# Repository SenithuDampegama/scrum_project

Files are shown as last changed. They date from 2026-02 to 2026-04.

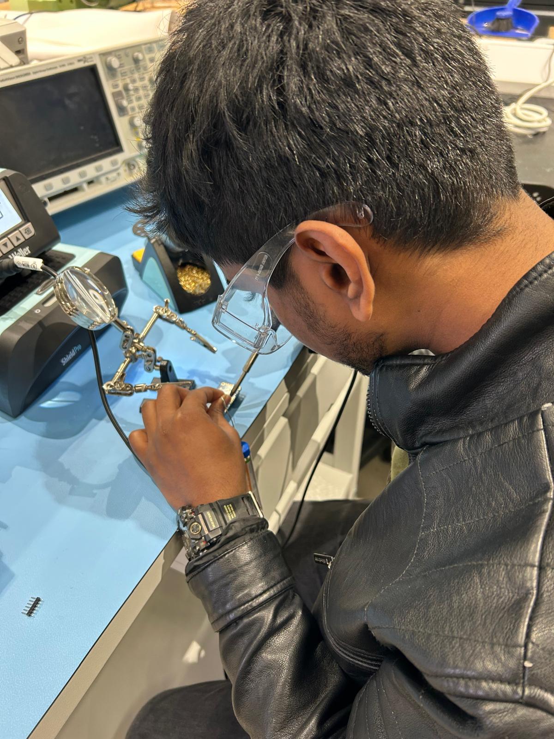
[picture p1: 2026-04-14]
docs/media/motor_controller/senithu.jpeg

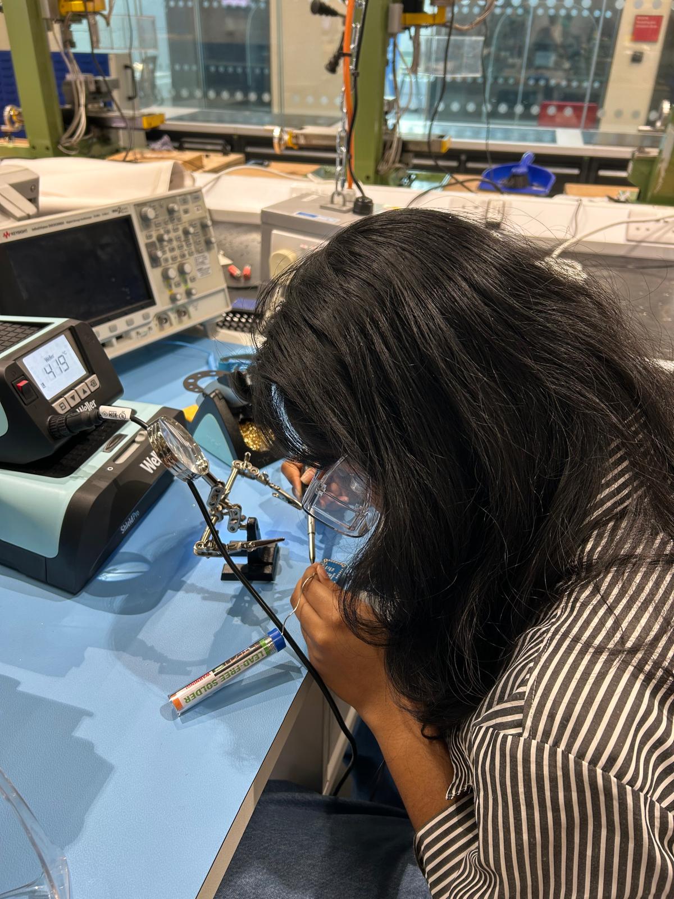
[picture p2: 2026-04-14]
docs/media/motor_controller/dinuli.jpeg

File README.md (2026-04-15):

# CDIO Scrum Robot Project



## Project Overview

This repository contains the implementation of a team-based robotics project developed under the **Conceive, Design, Implement, Operate (CDIO)** framework and managed using **Scrum** principles. The objective of the project is to design and build an autonomous walking robot capable of demonstrating multiple biologically inspired behaviours in a controlled environment.

The project was executed over **five sequential sprints**, each with a dedicated Scrum Master and a clearly defined set of deliverables. Although the development followed a logical engineering dependency order, Scrum artefacts such as sprint ownership, task tracking, and incremental delivery were maintained throughout the project.

---

## CDIO Tasks & Functional Requirements

The robot was required to satisfy the following core tasks:

* **Task 1 – Locomotion:** Enable the robot to walk using servo-driven mechanisms.
* **Task 2 – Object Avoidance:** Detect and avoid obstacles in the environment using distance sensors.
* **Task 3 – Phototaxis:** Move towards a bright light source and stop at approximately **20 cm** from it.
* **Task 4 – Predator Response:** Detect rapid motion in the environment, immediately stop movement, and deploy wings as a defensive response.

---

## Development Methodology

### CDIO Framework

The project followed the CDIO lifecycle:

* **Conceive:** System concept, behavioural definition, and mechanical feasibility analysis.
* **Design:** CAD modelling, electronics design, and system architecture definition.
* **Implement:** Hardware assembly, firmware development, and behaviour implementation.
* **Operate:** System testing, tuning, validation, and demonstration.

### Scrum Implementation

To align with Scrum methodology, the project was divided into **five sprints**, each led by a different Scrum Master. Each sprint produced tangible and reviewable outputs.

---

## Sprint Plan & Team Roles

| Sprint | Focus Area | Duration | Scrum Master |
| --- | --- | --- | --- |
| Sprint 1 | CAD Design | 4 weeks  | Dhanip Modi |
| Sprint 2 | Electronics Integration | 2 weeks  | Adwil Joshy |
| Sprint 3 | Robot Build | 1 week | Dinuli Jayaweera  |
| Sprint 4 | Programming & Behaviour Control | 2 weeks  | Senithu Dampegama |
| Sprint 5 | Testing & Validation | 1 week | Misba Babu |

The sprint order was selected to reflect real-world engineering dependencies, ensuring stable integration and reducing rework.

---

## Hardware Components

* Raspberry Pi Pico
* 10 × SG90 (180°) servo motors
* 2 × MG996R (360°) servo motors
* Adafruit BH1750 Light Sensor
* Adafruit PCA9685 Servo Driver
* Ultrasonic / IR distance sensors
* 9V battery and AA battery packs

---

## Software & Tools

* **Programming:** MicroPython / C++ (Pico)
* **CAD:** Fusion 360
* **Electronics Design:** Breadboard prototyping
* **Version Control:** Git & GitHub
* **Project Management:** GitHub Projects (Scrum Board)
* **Manufacturing:** 3D printing and laser cutting

---

## Repository Structure

```
cdio-scrum-robot/
├─ docs/                # Sprint documentation and reports
├─ cad/                 # CAD files and manufacturing exports
├─ electronics/         # Schematics, wiring, and BOM
├─ firmware/            # Pico firmware and control logic
├─ experiments/         # Calibration and tuning tests
└─ presentations/       # Final slides and demo media
```

---

## How to Run

1. Assemble the hardware according to the wiring diagrams in `electronics/`.
2. Flash the Raspberry Pi Pico with the firmware in `firmware/pico/`.
3. Power the system using the designated battery configuration.
4. Place the robot in a controlled environment with obstacles and a light source.

---

## Evidence & Demonstration

* Photos and videos of sprint deliverables are available in `docs/`.
* Final demonstration videos are available in `presentations/demo-videos/`.

---

## Project Management

All sprint tasks, issues, and progress tracking were managed using **GitHub Projects** following Scrum conventions. Each issue was labelled by sprint, owner, and task type.

---

## License

This project is released under the MIT License and is intended for academic and educational use only.

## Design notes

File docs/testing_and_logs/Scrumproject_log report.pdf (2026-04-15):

Student name
Total Sprints
Scrum Master | SPRINT 1 - Mechanical
Scrum Master | SPRINT 2 - Electronics
Scrum Master | SPRINT 3 - Robot Build
Scrum Master | SPRINT 4 - Software/Control
Scrum Master
Date | Work given | Name
3/2/2026 | Ordered Components in SPRINT 1 | Everyone
4th - 20th Feb | Components Designing Designing the Main body Sensor mountings Designing the Robot's Leg Designing the Wing Sprint 1 Review Submitted
4th - 20th Feb | | Modi Dhanip
4th - 20th Feb | | Adwil
4th - 20th Feb | | Dinuli
4th - 20th Feb | | Senithu
4th - 20th Feb | | Misba
17/02/2026
20/02/2026
Time Taken = 2 Week [24/03/2026 --> 09/03/2026]
Date | Work given | Name
24/2/2026 | Ordered Components in SPRINT 2 | Adwil
25/2/2026 | Soldering Motor controller Testing Ultrosonic sensors Testing Light sensor Testing servo motors Wiring of the robot Sprint 2 Review Submitted | Everyone
24/2/2026 | | Everyone
24/2/2026 | | Everyone
24/2/2026 | | Misba
3/3/2026 | | Dinuli
3/3/2026 | | Modi Dhanip
3/3/2026 | | Senithu, Adwil
6/3/2026 | | Adwil
Date | Work given | Name
10/3/2026 | No components were Ordered | Dinuli
9/3/2026 | MEETING 3- Planned for the Sprint 3 Wing attachment in Robot Build | Everyone
10/3/2026 | | Misba
10/3/2026 | Building the Lid of the robot Building the Legs of the Robot Connecting the Hip of the Robot Building the Main Body | Dinuli
10/3/2026 | | Modi Dhanip
10/3/2026 | | Senithu
10/3/2026 | | Adwil
20/03/2026 | Sprint 3 Review Submitted | Dinuli
Date | Work given | Name
17/03/2026 | No components were Ordered | Senithu
16/03/2026 | MEETING 4- Planned for the Programming week | Senithu
17th-24th Mar | Programming on predator Programming on Phototaxis Programming on Obstacle Avoidance Calibration of motors and Locomotion | dinuli
17th-24th Mar | | Modi Dhanip
17th-24th Mar | | Misba
17th-24th Mar | | Senithu
17th-24th Mar | Subsumption Sprint 4 Review Submitted | Adwil
27/03/2026 | | Senithu
Date | Work given | Name
10/4/2026 | Meeting 5- Planned for the Testing and Documentation Testing Locomotion and Calibration | Everyone
13/04/2026 | | Senithu
13/04/2026 | Testing Predator response code Testing Obstacle Avoidance | Dinuli
13/04/2026 | | Misba
13/04/2026 | Testing Phototaxis | Dhanip
14/04/2026 | GitHub, Wiring Diagram Gantt chart, Block Diagram | Senithu
14/04/2026 | | Dhanip
14/04/2026 | Flowchart, Hardware component List, Buy List | Misba
14/04/2026 | Presentation Slides | Adwil
14/04/2026 | Components list, Testing and Result List | Dinuli
17/04/2026 | Sprint 5 Review Submitted | Misba

5
Modi Dhanip
Adwil Joshy
Dinuli Jayaweera
Senithu Dampegama
Misba Fathima Babu
Time Taken = 4 Weeks [03/02/2026 --> 22/02/2026]

SPRINT 2 = ADWIL JOSHY

SPRINT 3 = DINULI

SPRINT 4 = SENITHU

SPRINT 5 = MISBA

Prepared Budget list for the components | Misba

MEETING 2- Discussed about the Electronics Soldering Light sensor, Motor controller

Modi Dhanip

Time Taken = 2 Week [17/03/2026 --> 27/03/2026]

Time Taken = 1 Week [13/04/2026 --> 19/04/2026]

Time Taken = 1 Week [10/03/2026 --> 16/03/2026]

SPRINT 1 = MODI DHANIP

MEETING 1- Discussed about the CAD design | Everyone

### SCRUM PROJECT LOG REPORT

DETAILS
Modi Dhanip, Senithu, Adwil, Dinuli, Misba

SPRINT 5 - Testing and Document

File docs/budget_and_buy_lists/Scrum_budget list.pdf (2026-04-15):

Category | Component | Quantity | Unit Cost (£) | Total Cost (£)
Electronics | Pico Board | 1 | £ 4.50 | £ 4.50
Electronics | SG90 Servo | 10 | £ 4.00 | £ 40.00
Electronics | BH1750 Light Sensor | 1 | £ 5.00 | £ 5.00
Electronics | HC-SR04 Ultrasonic | 2 | £ 2.00 | £ 4.00
Electronics | Micro USB Cable | 1 | £ 3.50 | £ 3.50
Electronics | Breadboard | 1 | £ 7.00 | £ 7.00
Manufacturing | 3D Printing (350g incl. buffer) | 230 | £ 0.02 | £ 4.60
Assembly | M3 Bolts (10mm) | 10 | £ 0.40 | £ 4.00
Assembly | M3 Bolts (30mm) | 3 | £ 0.50 | £ 1.50
Assembly | M3 Bolts (20 mm) | 4 | £ 0.45 | £ 1.80
Assembly | M3 Nuts | 13 | £ 0.05 | £ 0.65
Assembly | M3 Washers | 0 | £ 0.05 | £ -
Power | 4x AA Battery Holder | 1 | £ 1.50 | £ 1.50
Power | AA Batteries | 4 | £ 0.30 | £ 1.20
Power | 9V battery stud connector | 1 | £ 0.75 | £ 0.75
Power | PCA9685 motor controller | 1 | £ 15.00 | £ 15.00
| | | Subtotal | £ 95.00
| | | Contingency (20%)£ | 20.00

BUDGET LIST

Final Total | £ | 115.00

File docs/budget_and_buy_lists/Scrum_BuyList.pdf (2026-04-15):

Category | Component | Quantity | Unit Cost (£) | Total Cost (£)
Electronics | Pico Board | 1 | £ 4.50 | £ 4.50
Electronics | SG90 Servo | 10 | £ 4.00 | £ 40.00
Electronics | BH1750 Light Sensor | 1 | £ 5.00 | £ 5.00
Electronics | HC-SR04 Ultrasonic | 2 | £ 2.00 | £ 4.00
Electronics | Micro USB Cable | 1 | £ 3.50 | £ 3.50
Electronics | Breadboard | 1 | £ 7.00 | £ 7.00
Manufacturing | 3D Printing (350g incl. buffer) | 285.41 | £ 0.02 | £ 5.71
Assembly | M3 Bolts (10mm) | 10 | £ 0.40 | £ 4.00
Assembly | M3 Bolts (30mm) | 3 | £ 0.50 | £ 1.50
Assembly | M3 Bolts (20 mm) | 4 | £ 0.45 | £ 1.80
Assembly | M3 Nuts | 16 | £ 0.05 | £ 0.80
Assembly | M3 Washers | 11 | £ 0.05 | £ 0.55
Power | 4x AA Battery Holder | 1 | £ 1.50 | £ 1.50
Power | AA Batteries | 4 | £ 0.30 | £ 1.20
Power | 9V battery stud connector | 2 | £ 0.75 | £ 1.50
Power | PCA9685 motor controller | 1 | £ 15.00 | £ 15.00
| | | Subtotal | £ 97.56

BUY LIST

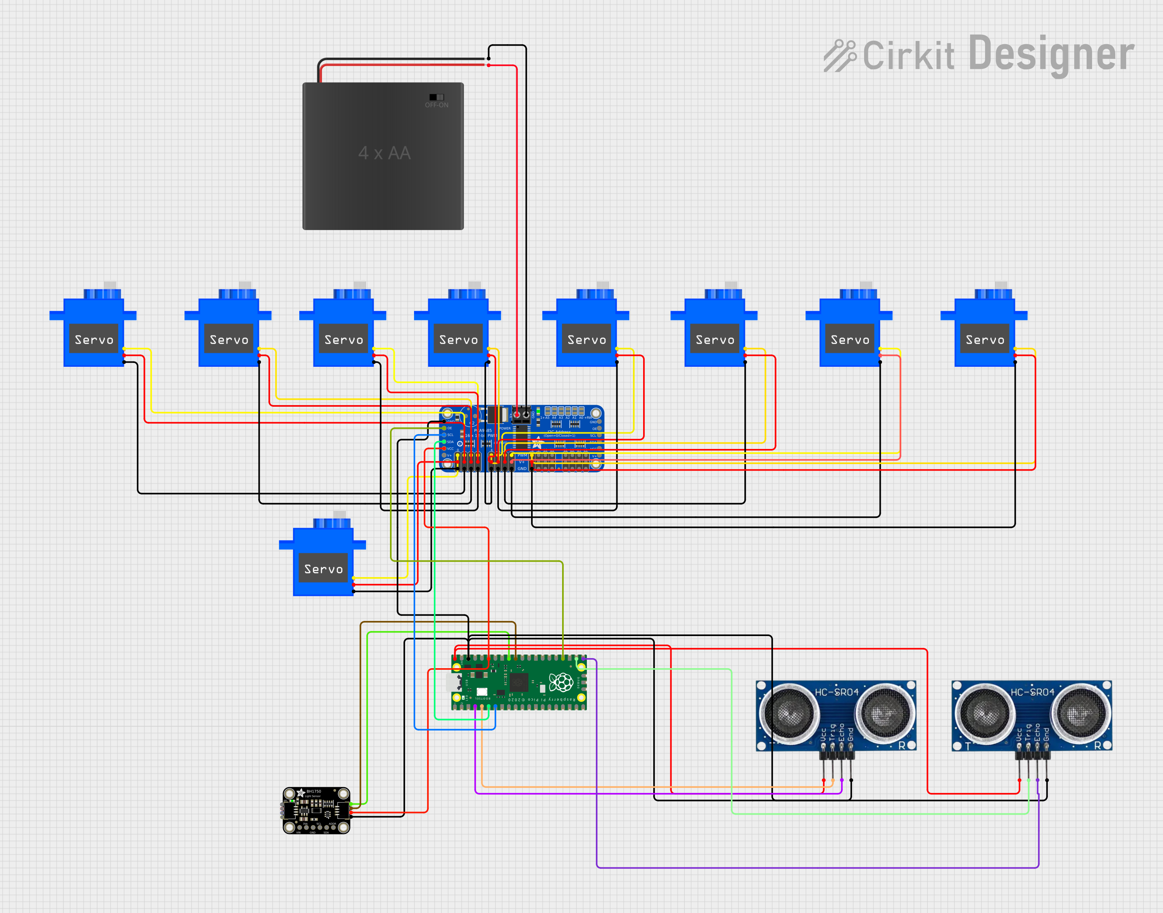
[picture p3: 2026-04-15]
docs/flowcharts_and_diagrams/circuit_image.png

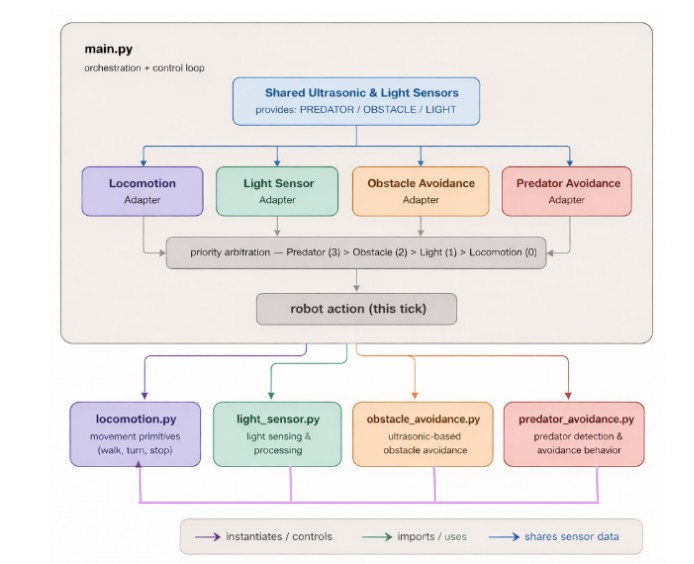
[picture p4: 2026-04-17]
docs/flowcharts_and_diagrams/Block_diagram.jpeg

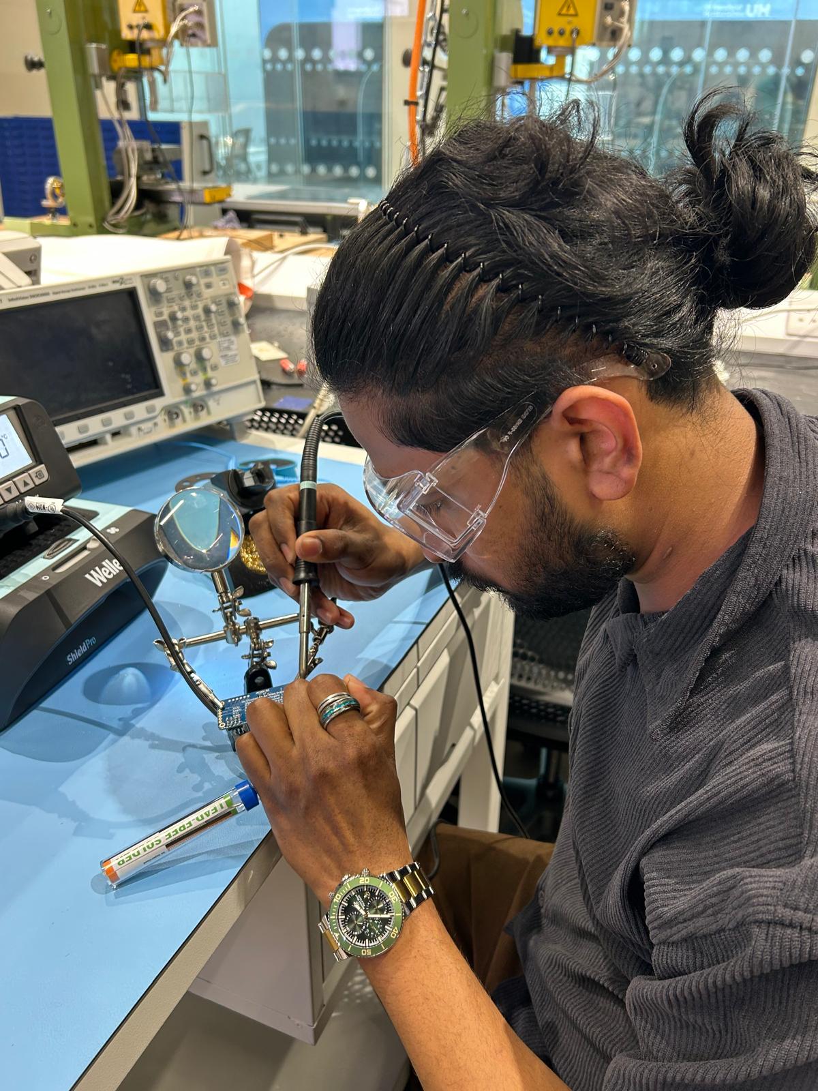
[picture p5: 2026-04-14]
docs/media/motor_controller/adwil.jpeg

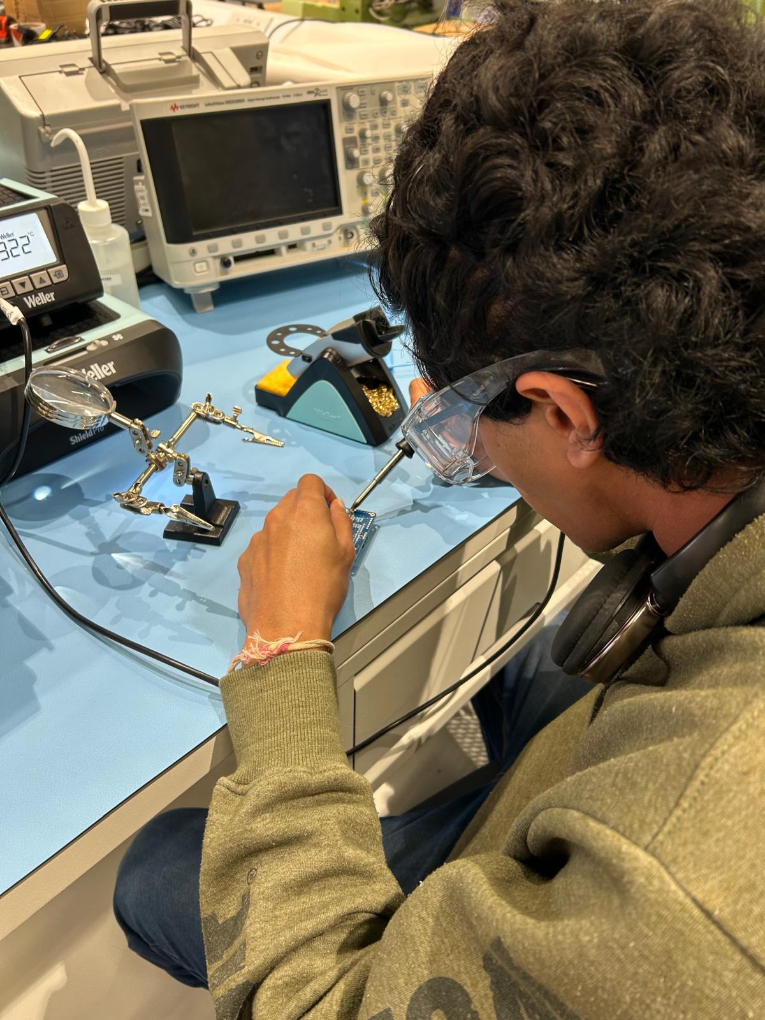
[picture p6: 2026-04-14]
docs/media/motor_controller/dhanip.jpeg

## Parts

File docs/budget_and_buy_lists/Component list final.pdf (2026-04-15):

Hardware Component List | No. of components
HC-SR04 Ultrasonic sensors | 2
BH1750 Light sensor | 1
Rasberry Pi Pico Board | 1
SG90 motors | 9
AA battery | 4
PCA9685 Motor Controller | 1
Battery Holder for 4 AA batteries | 1
9V battery stud connector | 1
Micro USB cable | 1
Total | 21

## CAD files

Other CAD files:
cad/components/Dhanip_Breadboard final - F1.f3d
cad/components/Dhanip_Microcontroller f.f3d
cad/components/Dhanip_light-sensor.f3d
cad/components/Dhanip_servo-arm.f3d
cad/components/Dhanip_servo-final.f3d
cad/components/Dinuli_Ultrasonic.f3d
cad/lid/Dinuli_Lid_Last.f3z
cad/locomotion/final_assembly/SENITHU_FINAL_ASSEMBLY.f3z
cad/locomotion/parts/SENITHU_ankel.f3d
cad/locomotion/parts/SENITHU_hip.f3d
cad/locomotion/parts/SENITHU_knee.f3d
cad/locomotion/parts/SENITHU_leg_L.f3d
cad/locomotion/parts/SENITHU_leg_R.f3d
cad/main_body/Adwil_Main_Body.f3z
cad/wing/Misba_Wing.f3d
cad/wing/Misba_Wing_Attachement.f3d

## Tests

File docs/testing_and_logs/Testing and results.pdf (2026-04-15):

. | Problems | Solutions

Sprint 1

Initially, we were not planning to use the motor controller, or the battery, therefore the design changed several times.

The design was changed, and we came up with integrating them on lid, so design of it was changed, and printed accordingly

The robot's height wasn't planned, and there was less space for the wires inside.

The robot height was adjusted and the body was reprinted with the correct height.
The wing had less width, and therefore was
fragile. | The wing width was fixed, and made sure it was strong.
Legs were initially bigger, causing friction. | The size of the legs was decreased and printed
The locations of the ultrasonic sensors, wings, light sensor were changed due to space management. | The locations were planned accordingly, space was
| managed, and the required CAD parts were printed on
| time.

Sprint 2

The power for the servos together wasn't enough | A separate power supply was used for servos, which was
| power supply from batteries.

Sprint 3

The connection of the wing and the body was
challenging since there was slight place in the wing connection.

We reduced the complexity by using equipments to handle the bolts.
The servo bolts were too small compared to the holes printed.

The materials were reprinted with smaller holes that fit into the bolt.

The robot was tested several times, as the wing motor started glitching, since the angles for it were wrong. Next, I tested the code several times, for changing the threshold values and finding the best values for the Sprint 4 robot. | The wing motor was replaced with the extra motor we bought, as the motor was burnt and not functioning well, and the angles were premeasured and adjsuted before it was integrated with the wing. To decide the threshold values, the test was carried out several times and decided.
The robot initially had an issue with moving slow, since there was larger friction. Once it was solved, there was a problem with the turnings, where the robot didn't make clear turns. | As a solution for the drag issue, the wave gate movement was shifted to crawl gate movement. The clear turns were made by finetuning the threshold values.

Sprint 5 | The robot is confusing the detections of obstacle and predator, since predator has the higher priority, obstacle avoidance doesn't override even when there is an obstacle. A subsumption is made in a way that both works.
| Subsumption architecture was changed as the previous Integration wasn't successful, as the priorities code had some issues. The new code works perfectly didn't work as expected according to the priorities.

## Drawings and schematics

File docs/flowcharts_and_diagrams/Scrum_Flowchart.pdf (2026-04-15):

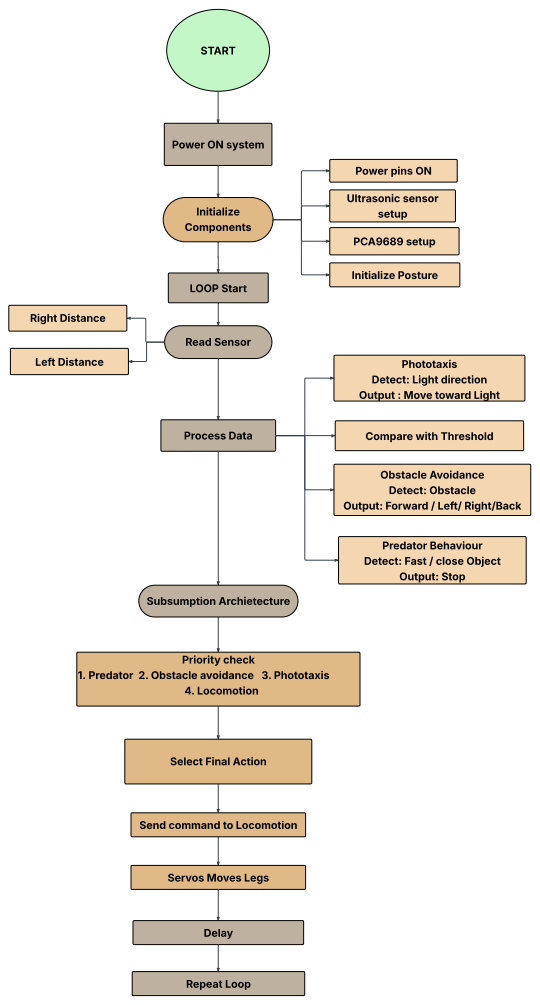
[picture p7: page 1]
START; Initialize Components; Ultrasonic sensor setup; PCA9689 setup; Initialize Posture; LOOP Start; Read Sensor; Left Distance; Right Distance; Process Data; Compare with Threshold; Subsumption Archietecture; Obstacle Avoidance Detect: Obstacle; Priority check; 4. Locomotion; Delay; Repeat Loop

Power ON system

Power pins ON

Phototaxis
Detect: Light direction
Output : Move toward Light

Output: Forward / Left/ Right/Back

Predator Behaviour
Detect: Fast / close Object
Output: Stop

1. Predator 2. Obstacle avoidance 3. Phototaxis

Select Final Action

Send command to Locomotion

Servos Moves Legs

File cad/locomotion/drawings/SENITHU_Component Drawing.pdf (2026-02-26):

A

2 | 3 | 4 | 5 | 6 | 7 | 8

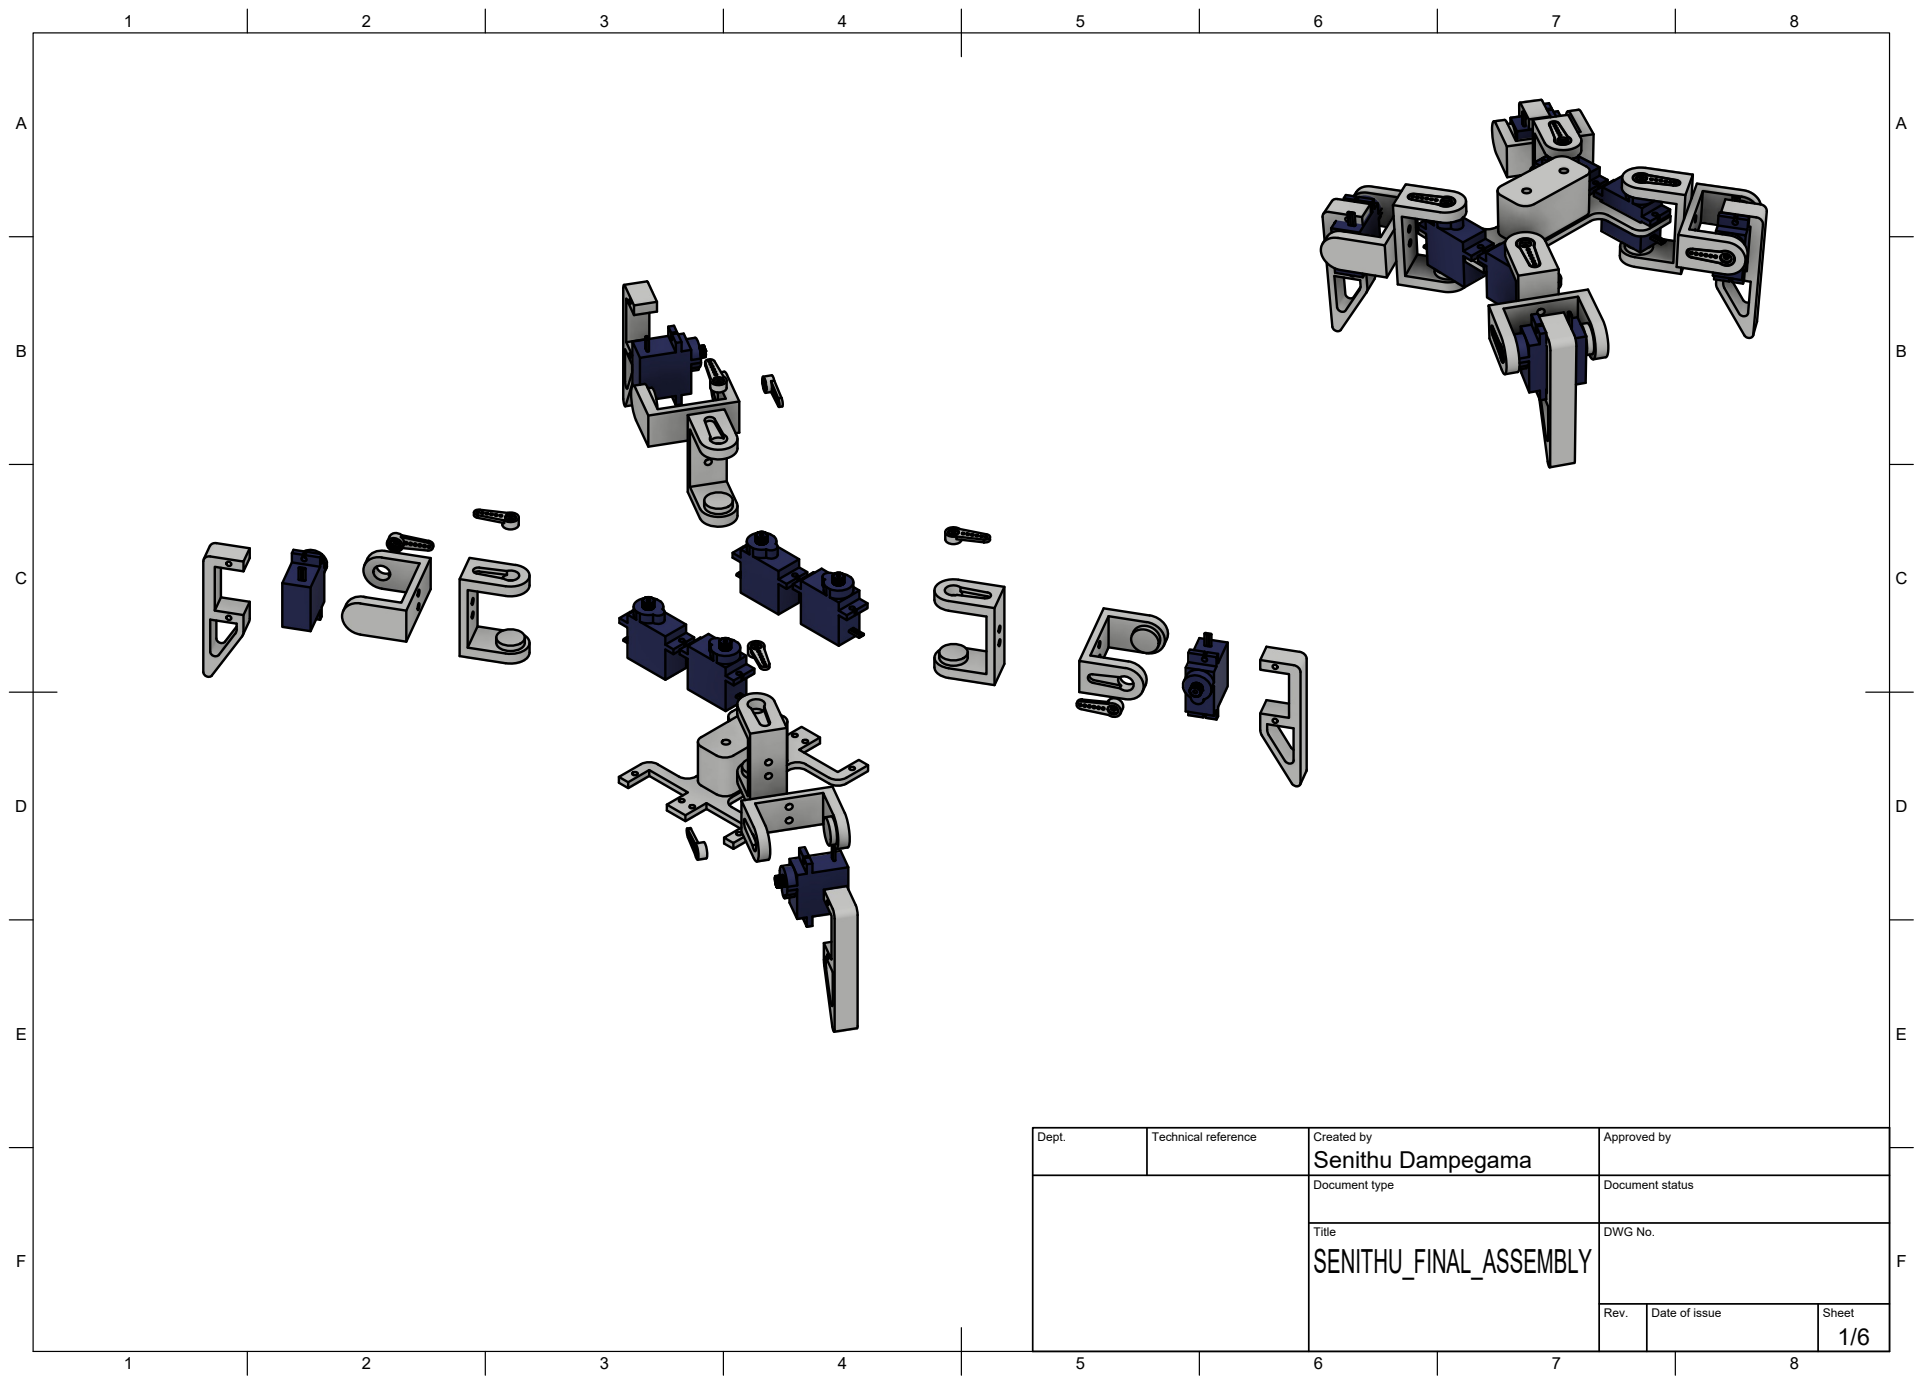
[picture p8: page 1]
Dept.; Technical reference; Created by; Approved by; Document type; Document status; Title; DWG No.; Rev.; Date of issue; Sheet; SENITHU_FINAL_ASSEMBLY; Senithu Dampegama

A

A

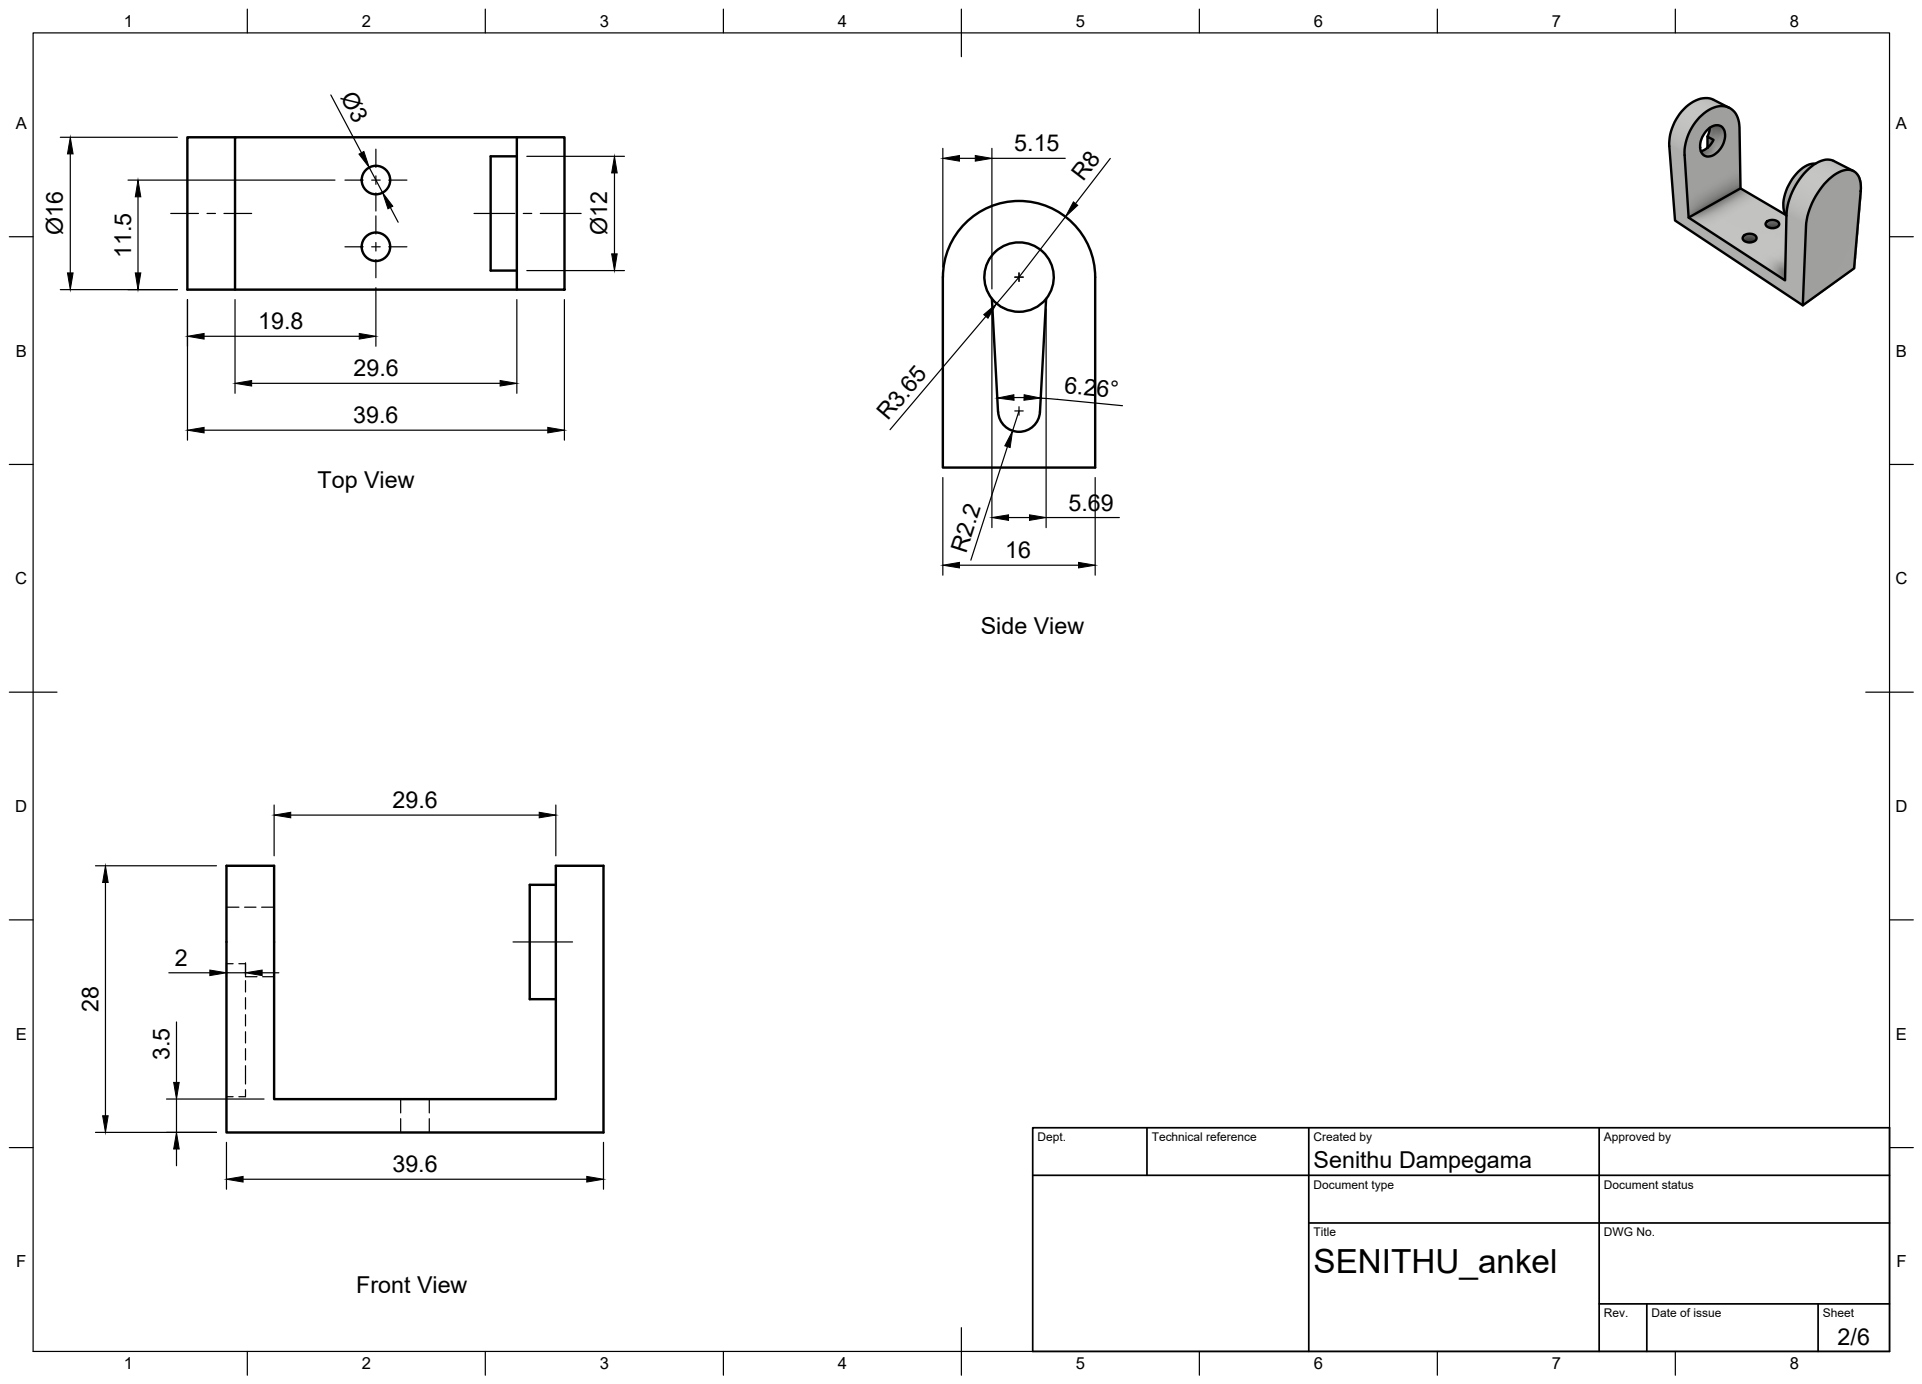
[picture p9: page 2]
Dept.; Technical reference; Created by; Approved by; Document type; Document status; Title; DWG No.; SENITHU_ankel; Senithu Dampegama; 39.6 Ø¹⁶; Ø¹²; Top View; Front View; Side View

A

A

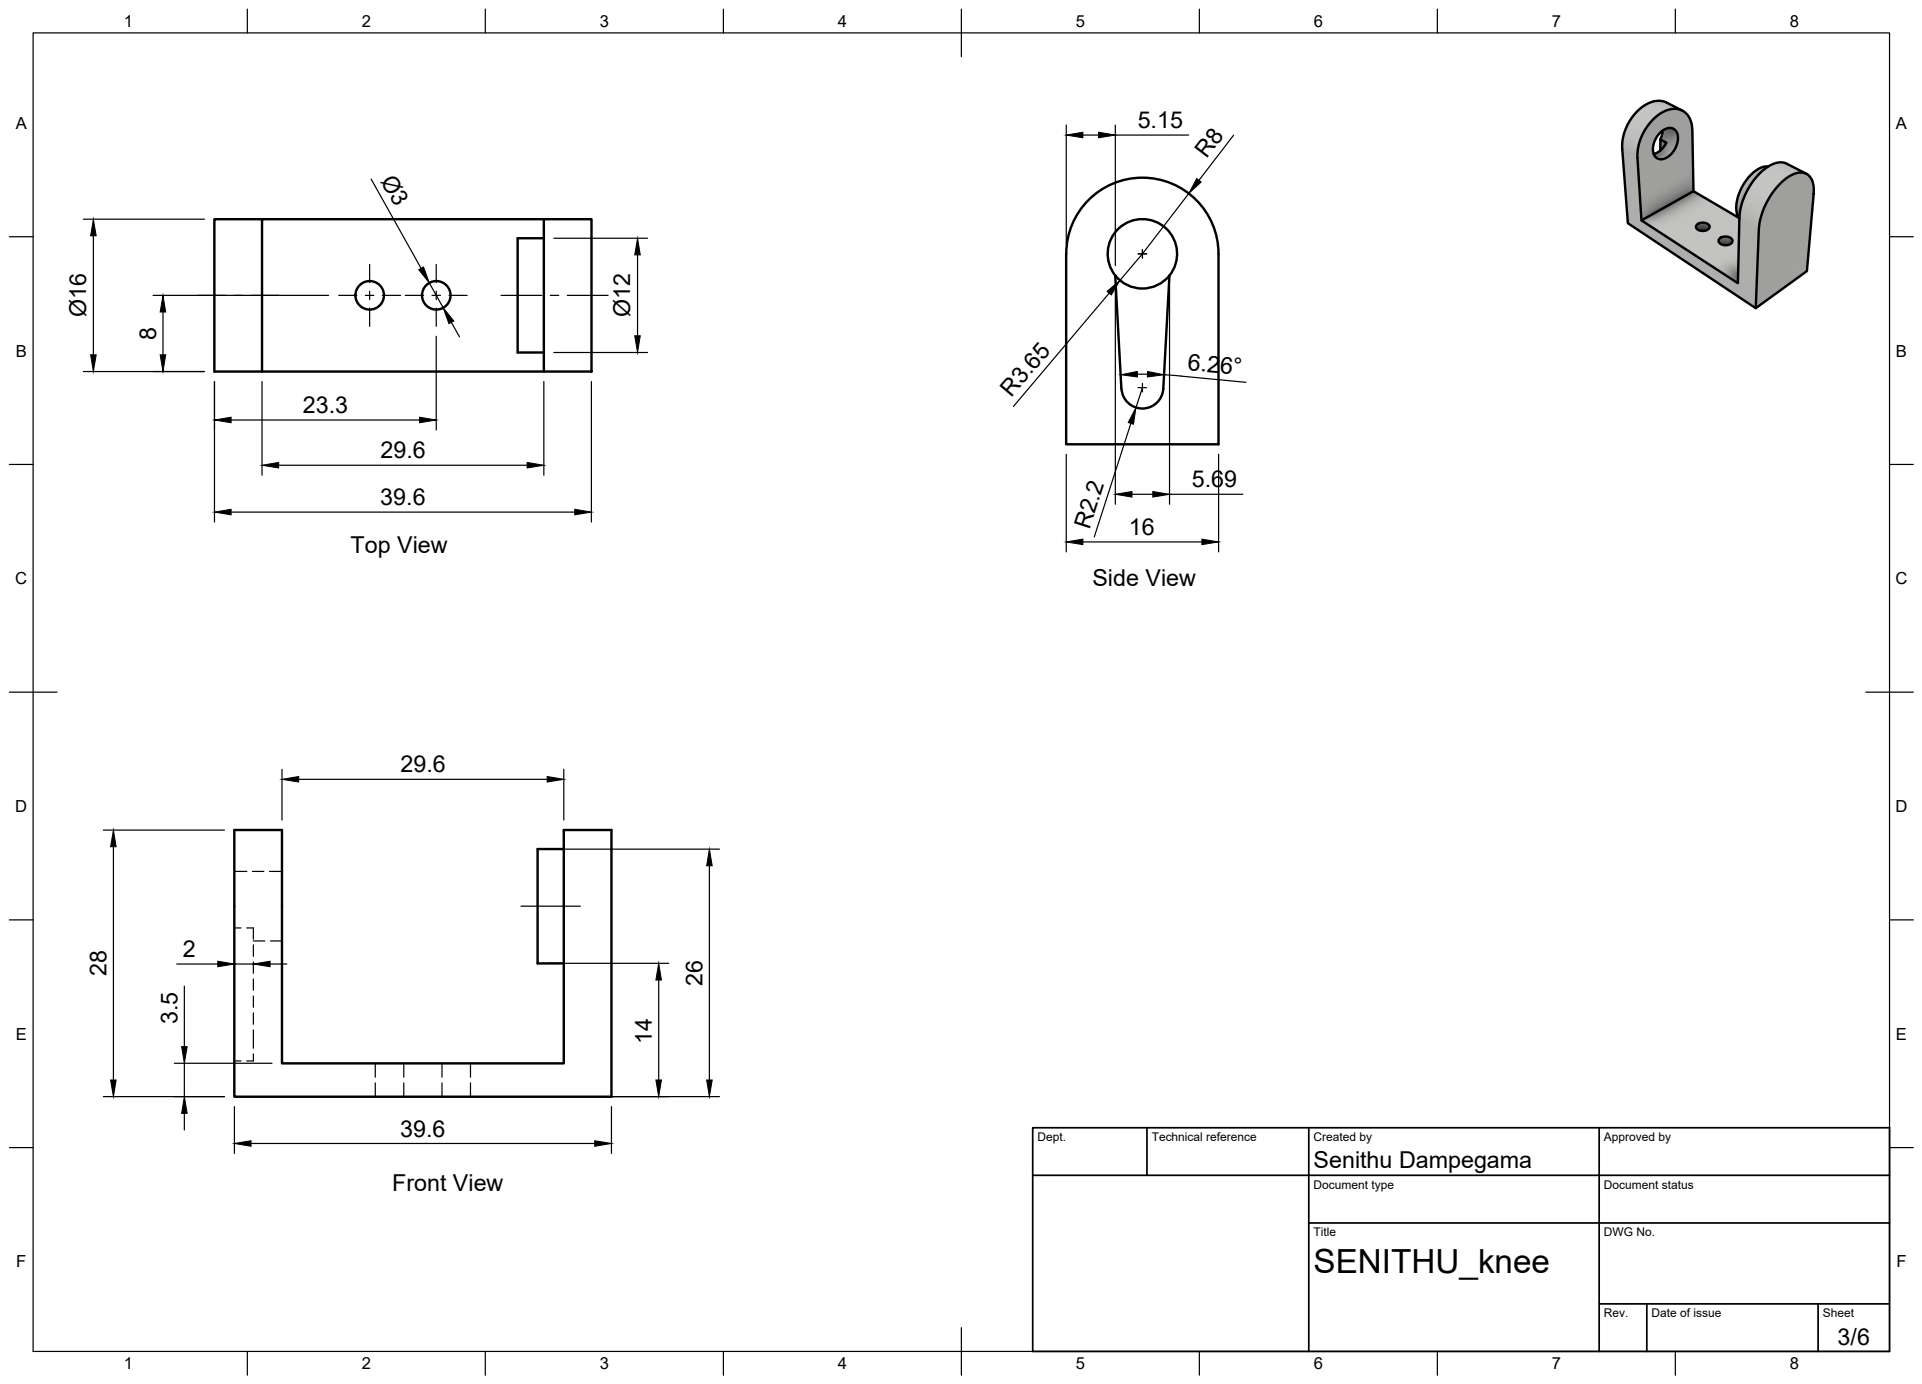
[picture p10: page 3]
Dept.; Technical reference; Created by; Approved by; Document type; Document status; Title; DWG No.; SENITHU_knee; Senithu Dampegama; 39.6 Ø¹⁶; Top View; Front View; Side View

A

A

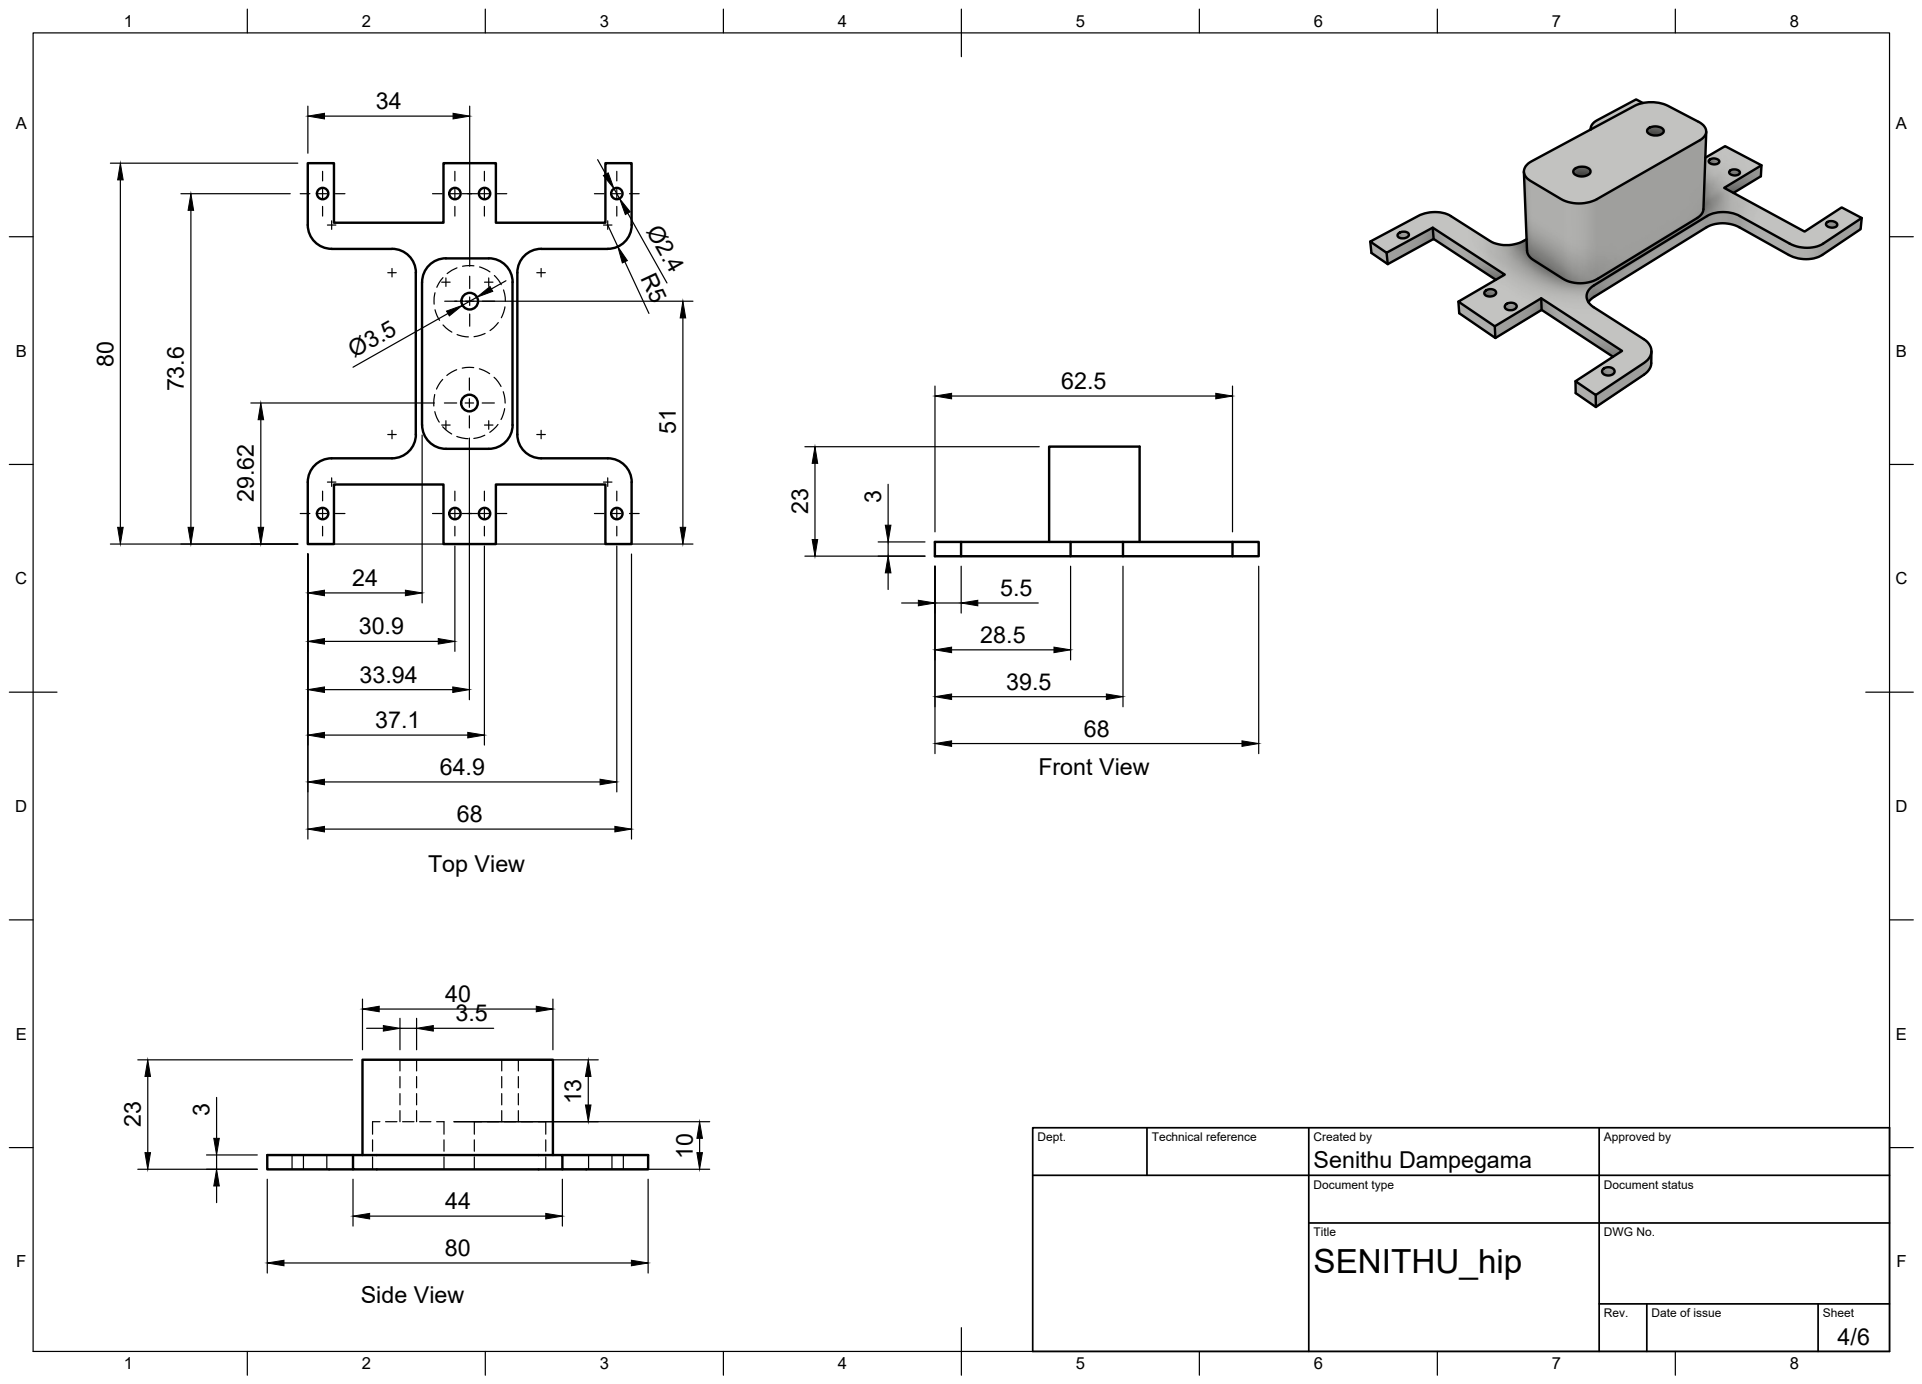
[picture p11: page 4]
Dept.; Technical reference; Created by; Approved by; Document type; Document status; Title; DWG No.; SENITHU_hip; Top View; Side View; Front View

Senithu Dampegama ⁸⁰

A

A

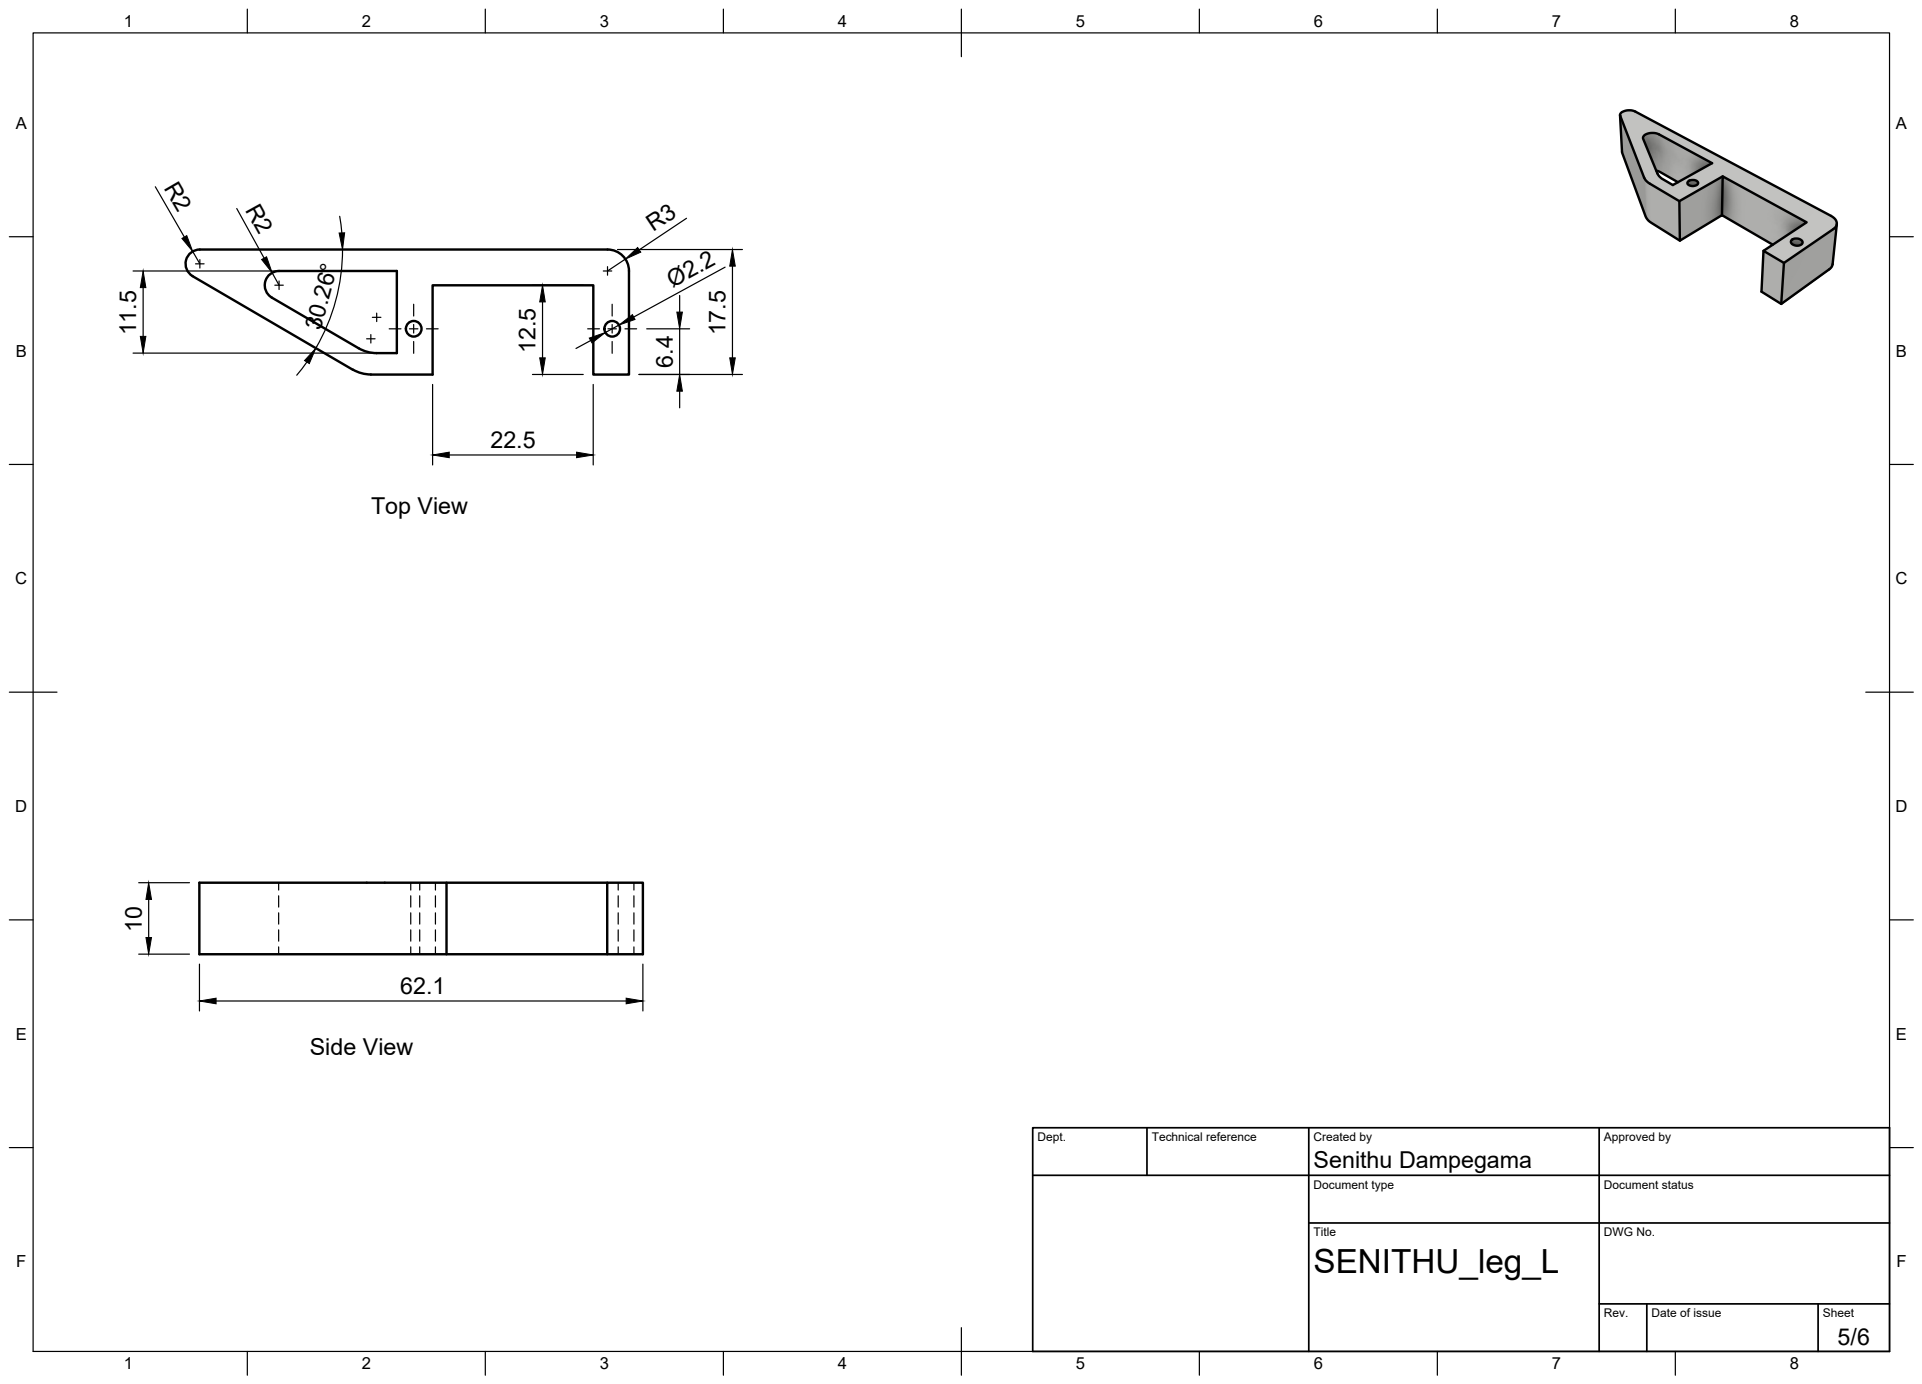
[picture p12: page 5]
Dept.; Technical reference; Created by; Approved by; Document type; Document status; Title; DWG No.; SENITHU_leg_L; Top View; Side View

Senithu Dampegama ¹⁷.5

A

A

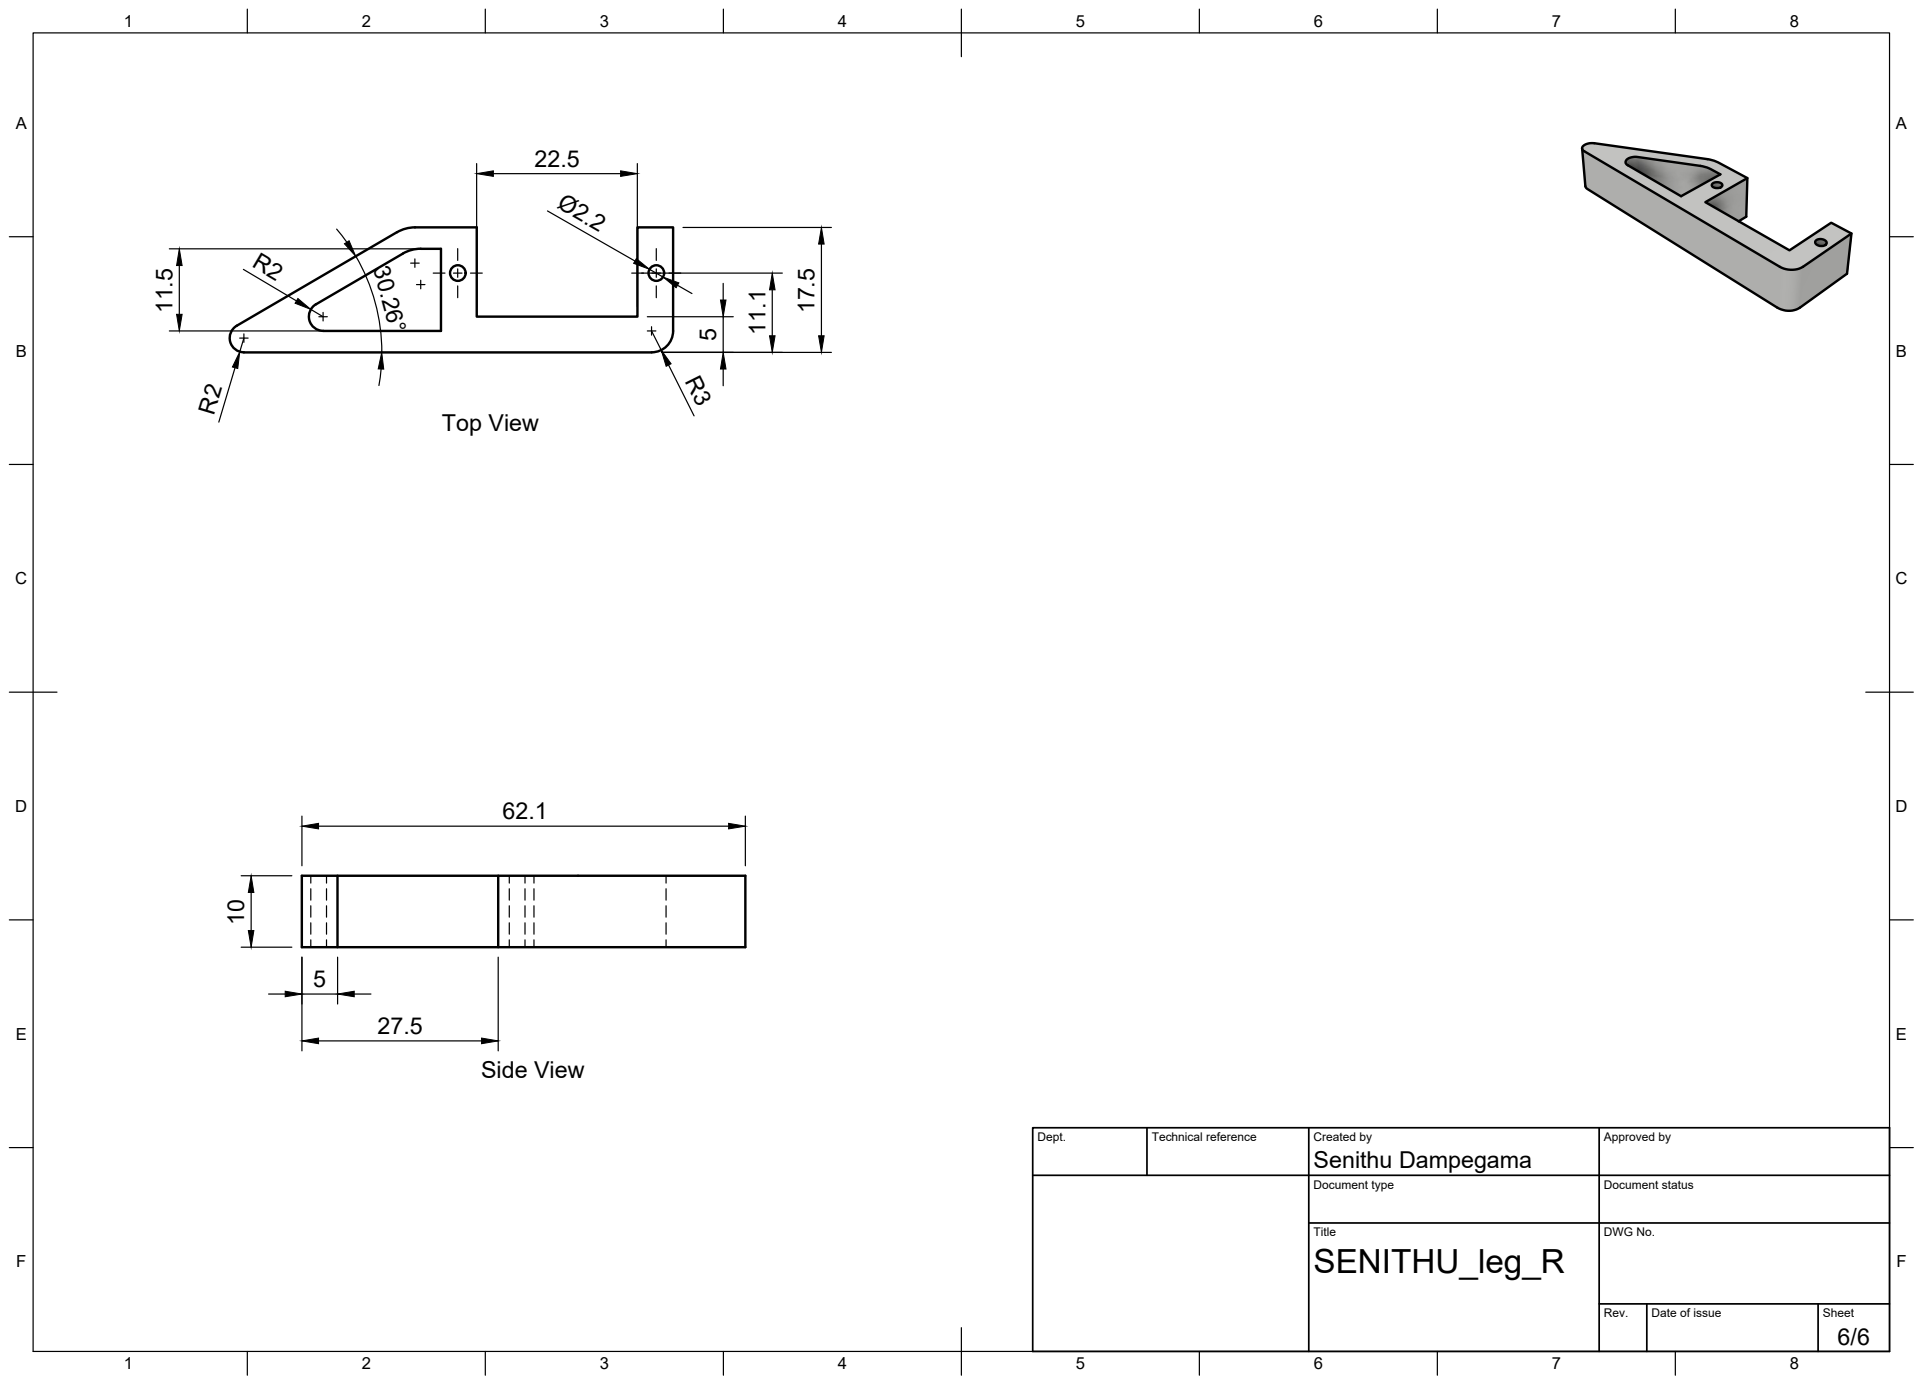
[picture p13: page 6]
Dept.; Technical reference; Created by; Approved by; Document type; Document status; Title; DWG No.; SENITHU_leg_R; Top View; Side View

Senithu Dampegama ¹⁷.5

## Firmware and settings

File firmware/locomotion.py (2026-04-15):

from machine import I2C, Pin
import time
import ujson


PCA9685_ADDR = 0x40
I2C_ID = 0
I2C_SDA_PIN = 4
I2C_SCL_PIN = 5
SERVO_FREQUENCY = 50
CALIBRATION_FILE = "calibration.json"
LEG_ORDER = ("FL", "FR", "RL", "RR")
CRAWL_SEQUENCE = ("FL", "RR", "FR", "RL")

# Edit channel wiring here if your robot is wired differently.
DEFAULT_CHANNEL_MAP = {
    "FL": {"hip": 1, "knee": 2},
    "FR": {"hip": 3, "knee": 4},
    "RL": {"hip": 5, "knee": 6},
    "RR": {"hip": 7, "knee": 8},
}

DEFAULT_CALIBRATION = {
    "FL": {"hip_home": 90, "knee_home": 15, "hip_sign": 1, "knee_lift_sign": 1},
    "FR": {"hip_home": 90, "knee_home": 15, "hip_sign": 1, "knee_lift_sign": 1},
    "RL": {"hip_home": 90, "knee_home": 15, "hip_sign": 1, "knee_lift_sign": 1},
    "RR": {"hip_home": 90, "knee_home": 15, "hip_sign": 1, "knee_lift_sign": 1},
}


def clamp_angle(angle):
    try:
        angle = int(angle)
    except:
        angle = 90
    return max(0, min(180, angle))


def clamp_sign(value, default_value=1):
    try:
        value = int(value)
    except:
        value = default_value
    return 1 if value >= 0 else -1


def copy_calibration(data):
    result = {}
    for leg in LEG_ORDER:
        leg_data = data.get(leg, {})
        result[leg] = {
            "hip_home": clamp_angle(
                leg_data.get(
                    "hip_home",
                    leg_data.get("hip", DEFAULT_CALIBRATION[leg]["hip_home"]),
                )
            ),
            "knee_home": clamp_angle(
                leg_data.get(
                    "knee_home",
                    leg_data.get("knee", DEFAULT_CALIBRATION[leg]["knee_home"]),
                )
            ),
            "hip_sign": clamp_sign(
                leg_data.get("hip_sign", DEFAULT_CALIBRATION[leg]["hip_sign"]),
                DEFAULT_CALIBRATION[leg]["hip_sign"],
            ),
            "knee_lift_sign": clamp_sign(
                leg_data.get(
                    "knee_lift_sign",
                    DEFAULT_CALIBRATION[leg]["knee_lift_sign"],
                ),
                DEFAULT_CALIBRATION[leg]["knee_lift_sign"],
            ),
        }
    return result


def load_calibration(filename=CALIBRATION_FILE):
    try:
        with open(filename, "r") as calibration_file:
            data = ujson.load(calibration_file)
        return copy_calibration(data)
    except:
        return copy_calibration(DEFAULT_CALIBRATION)


class PCA9685:
    MODE1 = 0x00
    PRESCALE = 0xFE
    LED0_ON_L = 0x06

    def __init__(self, i2c, address=PCA9685_ADDR, frequency=SERVO_FREQUENCY):
        self.i2c = i2c
        self.address = address
        self._write_reg(self.MODE1, 0x00)
        self.set_pwm_freq(frequency)

    def _write_reg(self, reg, value):
        self.i2c.writeto_mem(self.address, reg, bytes([value]))

    def _read_reg(self, reg):
        return self.i2c.readfrom_mem(self.address, reg, 1)[0]

    def set_pwm_freq(self, freq_hz):
        prescale = int(25000000.0 / (4096 * freq_hz) - 1 + 0.5)
        old_mode = self._read_reg(self.MODE1)
        self._write_reg(self.MODE1, (old_mode & 0x7F) | 0x10)
        self._write_reg(self.PRESCALE, prescale)
        self._write_reg(self.MODE1, old_mode)
        time.sleep_ms(5)
        self._write_reg(self.MODE1, old_mode | 0xA1)

    def set_pwm(self, channel, on_count, off_count):
        reg = self.LED0_ON_L + 4 * channel
        data = bytes((
            on_count & 0xFF,
            (on_count >> 8) & 0xFF,
            off_count & 0xFF,
            (off_count >> 8) & 0xFF,
        ))
        self.i2c.writeto_mem(self.address, reg, data)


class ServoDriver:
    def __init__(
        self,
        i2c=None,
        address=PCA9685_ADDR,
        frequency=SERVO_FREQUENCY,
        min_pulse_us=500,
        max_pulse_us=2500,
        frame_us=20000,
        smooth_steps=8,
        smooth_delay_ms=20,
    ):
        if i2c is None:
            i2c = I2C(
                I2C_ID,
                sda=Pin(I2C_SDA_PIN),
                scl=Pin(I2C_SCL_PIN),
                freq=400000,
            )
        self.frequency = frequency
        self.min_pulse_us = min_pulse_us
        self.max_pulse_us = max_pulse_us
        self.frame_us = frame_us
        self.smooth_steps = max(1, int(smooth_steps))
        self.smooth_delay_ms = max(0, int(smooth_delay_ms))
        self._pca = PCA9685(i2c, address, frequency=frequency)
        self._angles = {}

    def _angle_to_count(self, angle):
        angle = clamp_angle(angle)
        pulse_us = self.min_pulse_us + (
            (self.max_pulse_us - self.min_pulse_us) * angle / 180
        )
        return int(pulse_us * 4096 / self.frame_us)

    def set_angle(self, channel, angle):
        angle = clamp_angle(angle)
        self._pca.set_pwm(channel, 0, self._angle_to_count(angle))
        self._angles[channel] = angle

    def get_angle(self, channel):
        return self._angles.get(channel)

    def move_smooth(self, targets, steps=None, delay_ms=None):
        if not targets:
            return

        steps = self.smooth_steps if steps is None else max(1, int(steps))
        delay_ms = self.smooth_delay_ms if delay_ms is None else max(0, int(delay_ms))

        has_all_starts = True
        starts = {}
        for channel, target in targets.items():
            start = self.get_angle(channel)
            if start is None:
                has_all_starts = False
                break
            starts[channel] = start

        if not has_all_starts or steps <= 1:
            for channel, target in targets.items():
                self.set_angle(channel, target)
            return

        for step_index in range(1, steps + 1):
            for channel, target in targets.items():
                start = starts[channel]
                intermediate = start + (target - start) * step_index / steps
                self.set_angle(channel, intermediate)
            if delay_ms:
                time.sleep_ms(delay_ms)


class Leg:
    def __init__(
        self,
        name,
        driver,
        hip_channel,
        knee_channel,
        hip_home,
        knee_home,
        hip_sign,
        knee_lift_sign,
    ):
        self.name = name
        self.driver = driver
        self.hip_channel = hip_channel
        self.knee_channel = knee_channel
        self.hip_home = clamp_angle(hip_home)
        self.knee_home = clamp_angle(knee_home)
        self.hip_sign = clamp_sign(hip_sign)
        self.knee_lift_sign = clamp_sign(knee_lift_sign)
        self._hip_angle = self.hip_home
        self._knee_angle = self.knee_home

    def set_pose(self, hip_angle, knee_angle, smooth=False):
        hip_angle = clamp_angle(hip_angle)
        knee_angle = clamp_angle(knee_angle)
        if smooth:
            self.driver.move_smooth({
                self.hip_channel: hip_angle,
                self.knee_channel: knee_angle,
            })
        else:
            self.driver.set_angle(self.hip_channel, hip_angle)
            self.driver.set_angle(self.knee_channel, knee_angle)
        self._hip_angle = hip_angle
        self._knee_angle = knee_angle

    def home(self, smooth=False):
        self.set_pose(self.hip_home, self.knee_home, smooth=smooth)

    def current_pose(self):
        return {
            "hip_angle": self._hip_angle,
            "knee_angle": self._knee_angle,
        }


class QuadrupedLocomotion:
    def __init__(
        self,
        calibration_file=CALIBRATION_FILE,
        channel_map=None,
        swing_amount=30,
        lift_amount=15,
        support_push_amount=30,
        placed_leg_push_end=0,
        recovery_order=None,
        recover_threshold=10,
        settle_delay_ms=120,
        phase_delay_ms=160,
        push_substeps=2,
        turn_swing_amount=55,
        bow_front_extend_amount=10,
        bow_rear_support_amount=5,
        wave_swing_amount=10,
        servo_driver=None,
    ):
        self.channel_map = channel_map or DEFAULT_CHANNEL_MAP
        self.calibration = load_calibration(calibration_file)
        self.driver = servo_driver or ServoDriver()

        self.swing_amount = max(1, int(swing_amount))
        self.lift_amount = max(1, int(lift_amount))
        self.support_push_amount = max(1, int(support_push_amount))
        self.placed_leg_push_end = int(placed_leg_push_end)
        self.recover_threshold = max(0, int(recover_threshold))

        self.settle_delay_ms = max(0, int(settle_delay_ms))
        self.phase_delay_ms = max(0, int(phase_delay_ms))
        self.push_substeps = max(1, int(push_substeps))

        self.turn_swing_amount = max(1, int(turn_swing_amount))
        self.bow_front_extend_amount = max(0, int(bow_front_extend_amount))
        self.bow_rear_support_amount = max(0, int(bow_rear_support_amount))
        self.wave_swing_amount = max(1, int(wave_swing_amount))

        self.legs = self._create_legs()

        self.hip_offsets = {leg_name: 0 for leg_name in LEG_ORDER}
        self.knee_offsets = {leg_name: 0 for leg_name in LEG_ORDER}

        if recovery_order is None:
            self.recovery_order = CRAWL_SEQUENCE
        else:
            self.recovery_order = tuple(recovery_order)

    def _create_legs(self):
        legs = {}
        for leg_name in LEG_ORDER:
            leg_channels = self.channel_map[leg_name]
            leg_calibration = self.calibration[leg_name]
            legs[leg_name] = Leg(
                name=leg_name,
                driver=self.driver,
                hip_channel=leg_channels["hip"],
                knee_channel=leg_channels["knee"],
                hip_home=leg_calibration["hip_home"],
                knee_home=leg_calibration["knee_home"],
                hip_sign=leg_calibration["hip_sign"],
                knee_lift_sign=leg_calibration["knee_lift_sign"],
            )
        return legs

    def _delay(self):
        if self.phase_delay_ms:
            time.sleep_ms(self.phase_delay_ms)

    def _settle(self):
        if self.settle_delay_ms:
            time.sleep_ms(self.settle_delay_ms)

    def get_leg(self, leg_name):
        if leg_name not in self.legs:
            raise ValueError("Unknown leg: %s" % leg_name)
        return self.legs[leg_name]

    def _relative_to_absolute_hip(self, leg_name, hip_offset):
        leg = self.get_leg(leg_name)
        return clamp_angle(leg.hip_home + leg.hip_sign * hip_offset)

    def _relative_to_absolute_knee(self, leg_name, knee_offset):
        leg = self.get_leg(leg_name)
        return clamp_angle(leg.knee_home + leg.knee_lift_sign * knee_offset)

    def _apply_pose_targets(self, targets, smooth=True, steps=None):
        channel_targets = {}
        for leg_name, (hip_offset, knee_offset) in targets.items():
            leg = self.get_leg(leg_name)
            channel_targets[leg.hip_channel] = self._relative_to_absolute_hip(
                leg_name, hip_offset
            )
            channel_targets[leg.knee_channel] = self._relative_to_absolute_knee(
                leg_name, knee_offset
            )

        if smooth:
            self.driver.move_smooth(channel_targets, steps=steps)
        else:
            for channel, angle in channel_targets.items():
                self.driver.set_angle(channel, angle)

        for leg_name, (hip_offset, knee_offset) in targets.items():
            leg = self.get_leg(leg_name)
            self.hip_offsets[leg_name] = int(hip_offset)
            self.knee_offsets[leg_name] = int(knee_offset)
            leg._hip_angle = self._relative_to_absolute_hip(leg_name, hip_offset)
            leg._knee_angle = self._relative_to_absolute_knee(leg_name, knee_offset)

    def _set_leg_relative(self, leg_name, hip_offset=None, knee_offset=None, smooth=True):
        if hip_offset is None:
            hip_offset = self.hip_offsets[leg_name]
        if knee_offset is None:
            knee_offset = self.knee_offsets[leg_name]
        self._apply_pose_targets({
            leg_name: (hip_offset, knee_offset)
        }, smooth=smooth)

    def _move_hips_to_offsets(self, hip_targets, smooth=True):
        targets = {}
        for leg_name in hip_targets:
            targets[leg_name] = (hip_targets[leg_name], self.knee_offsets[leg_name])
        self._apply_pose_targets(targets, smooth=smooth)

    def _interpolate_hip_targets(self, hip_targets, steps):
        steps = max(1, int(steps))
        start_offsets = {}
        for leg_name, target in hip_targets.items():
            start_offsets[leg_name] = self.hip_offsets[leg_name]

        for step_index in range(1, steps + 1):
            partial_targets = {}
            for leg_name, target in hip_targets.items():
                start = start_offsets[leg_name]
                interpolated = start + (target - start) * step_index / steps
                partial_targets[leg_name] = int(round(interpolated))
            self._move_hips_to_offsets(partial_targets, smooth=True)
            self._delay()

    def _push_phase(self, stepping_leg_name, direction):
        """
        direction = +1 for forward walking
        direction = -1 for backward walking

        stepping leg:
            from forward swing position toward placed_leg_push_end
        support legs:
            pushed backward on ground
        """
        hip_targets = {}
        for leg_name in LEG_ORDER:
            if leg_name == stepping_leg_name:
                hip_targets[leg_name] = direction * self.placed_leg_push_end
            else:
                hip_targets[leg_name] = -direction * self.support_push_amount

        self._interpolate_hip_targets(hip_targets, self.push_substeps)

    def _needs_recovery(self, leg_name, direction):
        hip_offset = self.hip_offsets[leg_name]
        return (direction * hip_offset) < -self.recover_threshold

    def _recover_leg_to_home(self, leg_name):
        """
        Recovery rule:
        - lift leg
        - move hip back to home (0) in air
        - place down
        """
        current_hip = self.hip_offsets[leg_name]

        if current_hip == 0 and self.knee_offsets[leg_name] == 0:
            return

        # lift
        self._set_leg_relative(
            leg_name,
            hip_offset=current_hip,
            knee_offset=self.lift_amount,
            smooth=True,
        )
        self._settle()

        # move hip to home while lifted
        self._set_leg_relative(
            leg_name,
            hip_offset=0,
            knee_offset=self.lift_amount,
            smooth=True,
        )
        self._settle()

        # place
        self._set_leg_relative(
            leg_name,
            hip_offset=0,
            knee_offset=0,
            smooth=True,
        )
        self._settle()

    def _recovery_phase(self, stepping_leg_name, direction):
        """
        Recover legs one by one, lifted, back to home.
        We skip the stepping leg here because it has just been placed and pushed.
        """
        for leg_name in self.recovery_order:
            if leg_name == stepping_leg_name:
                continue
            if self._needs_recovery(leg_name, direction):
                self._recover_leg_to_home(leg_name)

    def _execute_step(self, stepping_leg_name, direction):
        """
        Hybrid gait:
        1. Lift stepping leg
        2. Swing stepping leg forward in air
        3. Place stepping leg
        4. Push phase
        5. Recover over-back support legs one by one while lifted
        """
        swing_target = direction * self.swing_amount

        # 1. Lift stepping leg
        self._set_leg_relative(
            stepping_leg_name,
            hip_offset=self.hip_offsets[stepping_leg_name],
            knee_offset=self.lift_amount,
            smooth=True,
        )
        self._settle()

        # 2. Swing stepping leg forward in air
        self._set_leg_relative(
            stepping_leg_name,
            hip_offset=swing_target,
            knee_offset=self.lift_amount,
            smooth=True,
        )
        self._settle()

        # 3. Place stepping leg
        self._set_leg_relative(
            stepping_leg_name,
            hip_offset=swing_target,
            knee_offset=0,
            smooth=True,
        )
        self._settle()

        # 4. Push phase
        self._push_phase(stepping_leg_name, direction)

        # 5. Recovery phase (leg by leg, lifted)
        self._recovery_phase(stepping_leg_name, direction)

    def _crawl_cycle(self, direction_provider, steps):
        steps = max(0, int(steps))
        for _ in range(steps):
            for leg_name in CRAWL_SEQUENCE:
                direction = direction_provider(leg_name)
                self._execute_step(leg_name, direction)

    def _execute_step_interruptible(self, stepping_leg_name, direction, should_interrupt):
        """
        Same as _execute_step but checks should_interrupt() between
        each of the 5 phases. Returns True if interrupted.
        Robot is left in a safe standing position if interrupted.
        """
        swing_target = direction * self.swing_amount

        # 1. Lift stepping leg
        self._set_leg_relative(
            stepping_leg_name,
            hip_offset=self.hip_offsets[stepping_leg_name],
            knee_offset=self.lift_amount,
            smooth=True,
        )
        self._settle()
        if should_interrupt():
            self.stand(smooth=False)
            return True

        # 2. Swing stepping leg forward in air
        self._set_leg_relative(
            stepping_leg_name,
            hip_offset=swing_target,
            knee_offset=self.lift_amount,
            smooth=True,
        )
        self._settle()
        if should_interrupt():
            self.stand(smooth=False)
            return True

        # 3. Place stepping leg
        self._set_leg_relative(
            stepping_leg_name,
            hip_offset=swing_target,
            knee_offset=0,
            smooth=True,
        )
        self._settle()
        if should_interrupt():
            self.stand(smooth=False)
            return True

        # 4. Push phase
        self._push_phase(stepping_leg_name, direction)
        if should_interrupt():
            self.stand(smooth=False)
            return True

        # 5. Recovery phase
        self._recovery_phase(stepping_leg_name, direction)

        return False

    def _crawl_cycle_interruptible(self, direction_provider, steps, should_interrupt):
        """
        Same as _crawl_cycle but checks should_interrupt() between
        each phase of every leg movement. If it returns True, the robot
        stands immediately and returns True to signal interruption.
        """
        steps = max(0, int(steps))
        for _ in range(steps):
            for leg_name in CRAWL_SEQUENCE:
                if should_interrupt():
                    self.stand(smooth=False)
                    return True
                direction = direction_provider(leg_name)
                interrupted = self._execute_step_interruptible(
                    leg_name, direction, should_interrupt
                )
                if interrupted:
                    return True
        return False

    def walk_forward_interruptible(self, steps=1, should_interrupt=None):
        """
        Walk forward but stop immediately between leg movements
        if should_interrupt() returns True.
        Returns True if interrupted, False if completed normally.
        """
        if should_interrupt is None:
            return self.walk_forward(steps)
        self.stand(smooth=True)
        self._delay()
        return self._crawl_cycle_interruptible(
            lambda leg_name: 1, steps, should_interrupt
        )

    def stand(self, smooth=True):
        targets = {}
        for leg_name in LEG_ORDER:
            targets[leg_name] = (0, 0)
        self._apply_pose_targets(targets, smooth=smooth)
        return self

    def walk_forward(self, steps=1, stand_before=True, stand_after=False):
        if stand_before:
            self.stand(smooth=True)
            self._delay()
        self._crawl_cycle(lambda leg_name: 1, steps)
        if stand_after:
            self.stand(smooth=True)
        return self

    def walk_backward(self, steps=1, stand_before=True, stand_after=False):
        if stand_before:
            self.stand(smooth=True)
            self._delay()
        self._crawl_cycle(lambda leg_name: -1, steps)
        if stand_after:
            self.stand(smooth=True)
        return self

    def turn_left(self, steps=1, stand_before=True, stand_after=False):
        if stand_before:
            self.stand(smooth=True)
            self._delay()

        def left_turn_direction(leg_name):
            if leg_name in ("FR", "RR"):
                return 1
            return -1

        saved_swing = self.swing_amount
        saved_push = self.support_push_amount

        self.swing_amount = self.turn_swing_amount
        self.support_push_amount = self.turn_swing_amount

        self._crawl_cycle(left_turn_direction, steps)

        self.swing_amount = saved_swing
        self.support_push_amount = saved_push

        if stand_after:
            self.stand(smooth=True)
        return self

    def turn_right(self, steps=1, stand_before=True, stand_after=False):
        if stand_before:
            self.stand(smooth=True)
            self._delay()

        def right_turn_direction(leg_name):
            if leg_name in ("FL", "RL"):
                return 1
            return -1

        saved_swing = self.swing_amount
        saved_push = self.support_push_amount

        self.swing_amount = self.turn_swing_amount
        self.support_push_amount = self.turn_swing_amount

        self._crawl_cycle(right_turn_direction, steps)

        self.swing_amount = saved_swing
        self.support_push_amount = saved_push

        if stand_after:
            self.stand(smooth=True)
        return self

    def bow(self, smooth=True):
        self.stand(smooth=smooth)
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

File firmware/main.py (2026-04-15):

from machine import Pin, I2C
import time

from locomotion import QuadrupedLocomotion
import light_sensor
from light_sensor import LightNavigator
from obstacle_avoidance import ObstacleAvoidance
from predator_avoidance import Robot as PredatorRobot

TICK_MS = 50


# --- Shared ultrasonic reader using predator's get_distance (30000us timeout) ---
class SharedUltrasonicReader:
    def __init__(self, obstacle: ObstacleAvoidance, predator: PredatorRobot):
        self._obstacle = obstacle
        self._predator = predator
        self.left_d  = 999
        self.right_d = 999
        self.classification = "CLEAR"  # "CLEAR", "OBSTACLE", "PREDATOR", "BOTH"

    def update(self):
        p = self._predator
        # Use predator's get_distance — 30000us timeout, more reliable
        self.left_d  = p.get_distance(p.trigL, p.echoL) or 999
        time.sleep_ms(30)
        self.right_d = p.get_distance(p.trigR, p.echoR) or 999

        obs_left   = self.left_d  < self._obstacle.threshold   # 20cm
        obs_right  = self.right_d < self._obstacle.threshold   # 20cm
        pred_left  = self.left_d  < p.LEFT_THRESHOLD           # 50cm
        pred_right = self.right_d < p.RIGHT_THRESHOLD          # 50cm

        is_obstacle = obs_left or obs_right
        is_predator = pred_left or pred_right

        if is_obstacle and is_predator:
            self.classification = "BOTH"
        elif is_obstacle:
            self.classification = "OBSTACLE"
        elif is_predator:
            self.classification = "PREDATOR"
        else:
            self.classification = "CLEAR"

        print("[SENSOR] L:{:.1f} R:{:.1f} -> {}".format(
            self.left_d, self.right_d, self.classification))


class LocomotionAdapter:
    def __init__(self, robot: QuadrupedLocomotion, interrupt_checks=None):
        self._robot  = robot
        self._checks = interrupt_checks or []

    def check(self) -> bool:
        return True

    def _should_interrupt(self):
        return any(check() for check in self._checks)

    def execute(self):
        interrupted = self._robot.walk_forward_interruptible(
            steps=1,
            should_interrupt=self._should_interrupt
        )
        if interrupted:
            print("[ARB] Locomotion interrupted by higher priority layer")


class PhototaxisAdapter:
    def __init__(self, navigator: LightNavigator, interrupt_checks=None):
        self._nav    = navigator
        self._leak   = 0.0
        self._checks = interrupt_checks or []
        self._lux    = 0.0

    def _should_interrupt(self):
        return any(check() for check in self._checks)

    def check(self) -> bool:
        self._lux = self._nav.read_lux()
        print(self._lux)

        if self._lux > 450:
            self._leak = -999  # sentinel for goback
            return True

        if self._lux < 320:
            self._leak = self._nav.compute_leak(self._lux)
            return abs(self._leak) > 0.05

        # Stable light range (320-450): no action
        self._leak = 0.0
        return False

    def execute(self):
        if self._lux > 450:
            self._nav.goback()
        elif self._lux < 320:
            self._nav.decide_action(self._leak)
        else:
            self._nav.stop()


class ObstacleAdapter:
    def __init__(self, obstacle: ObstacleAvoidance, shared: SharedUltrasonicReader):
        self._obstacle      = obstacle
        self._shared        = shared
        self._left_blocked  = False
        self._right_blocked = False

    def check(self) -> bool:
        # Only do real work if classification suggests obstacle range
        if self._shared.classification not in ("OBSTACLE", "BOTH"):
            self._left_blocked  = False
            self._right_blocked = False
            return False

        self._left_blocked  = self._shared.left_d  < self._obstacle.threshold
        self._right_blocked = self._shared.right_d < self._obstacle.threshold
        return self._left_blocked or self._right_blocked

    def execute(self):
        o = self._obstacle
        if self._left_blocked and self._right_blocked:
            o.robot.walk_backward(1)
        elif self._left_blocked:
            o.robot.turn_right(1)
        elif self._right_blocked:
            o.robot.turn_left(1)


class PredatorAdapter:
    def __init__(self, predator: PredatorRobot, shared: SharedUltrasonicReader):
        self._predator    = predator
        self._shared      = shared
        self._triggered   = False
        self._last_motion = None
        self._last_speed  = 0

    def check(self) -> bool:
        L = self._shared.left_d
        R = self._shared.right_d

        # Always run speed check — fast approach may not be close enough yet
        triggered, motion, speed = self._predator.check_predator_from(L, R)

        # If speed check didn't trigger, use proximity fallback
        # only when classification suggests predator range
        if not triggered and self._shared.classification in ("PREDATOR", "BOTH"):
            left  = L < self._predator.LEFT_THRESHOLD
            right = R < self._predator.RIGHT_THRESHOLD
            if (left or right) and speed > 0:  # only if actually approaching
                diff = abs(L - R)
                if left and right and diff < self._predator.FRONT_DIFF_THRESHOLD:
                    motion = "FRONT"
                elif left:
                    motion = "LEFT"
                else:
                    motion = "RIGHT"
                triggered = True

        self._triggered   = triggered
        self._last_motion = motion
        self._last_speed  = speed
        return triggered

    def quick_check(self) -> bool:
        L = self._shared.left_d
        R = self._shared.right_d
        if L is None or R is None:
            return False
        return L < self._predator.LEFT_THRESHOLD or R < self._predator.RIGHT_THRESHOLD

    def execute(self):
        if self._triggered:
            self._predator.act_predator(self._last_motion, self._last_speed)
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
